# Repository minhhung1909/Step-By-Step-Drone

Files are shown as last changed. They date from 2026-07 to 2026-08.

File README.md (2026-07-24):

### 🚀 Day 1: Power Management Architecture & Schematic Design
* **Fixed & Verified Output Rails**: Finalized the power tree architecture for the 4-in-1 FOC ESC[cite: 1].
* **Buck Converter Stage (MP2359)**: Configured the step-down regulator to efficiently drop the main battery voltage down to a stable 5V rail.
* **LDO Linear Regulator Stage (MIC5219-3.3)**: Integrated the ultra-low noise LDO to convert 5V to 3.3V, ensuring a clean analog supply (`VDDA`) for the STM32G431 MCU and preventing FOC current-sensing noise.
* **Schematic Captures**: 
  * Configured proper bootstrapping components and decoupling/filtering capacitors.
  * Set up component attributes (such as DNP for optional feed-forward configurations) to keep the BOM clean for manufacturing.

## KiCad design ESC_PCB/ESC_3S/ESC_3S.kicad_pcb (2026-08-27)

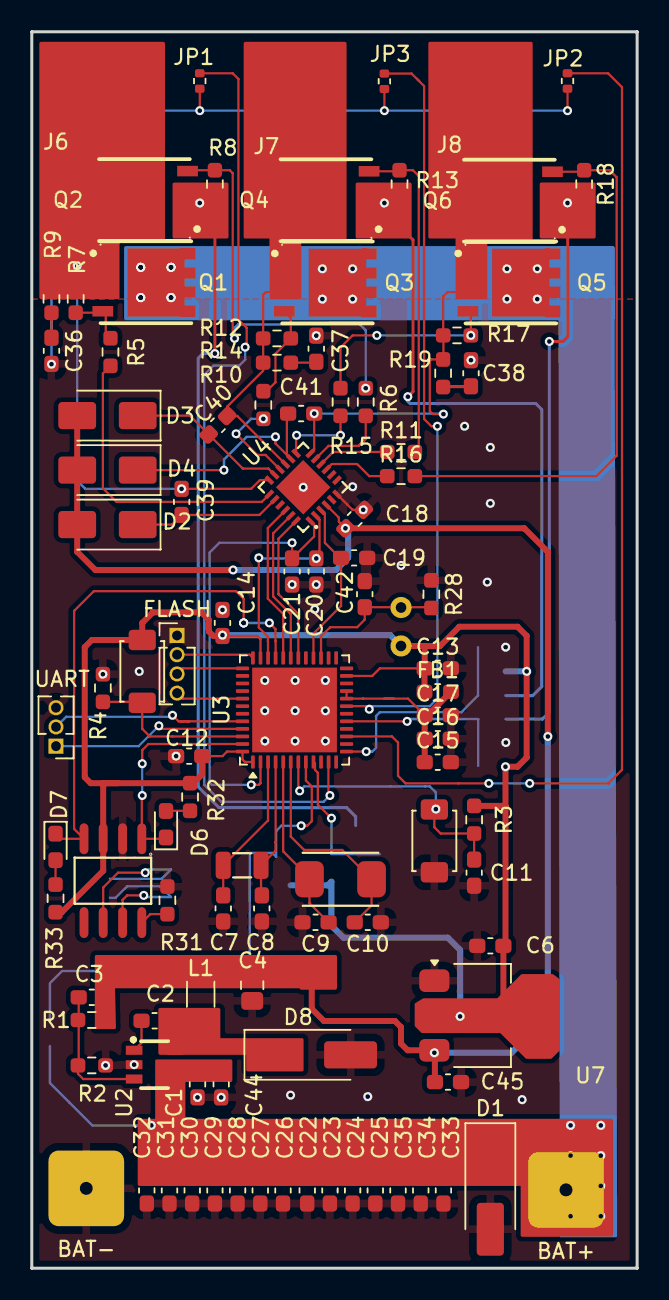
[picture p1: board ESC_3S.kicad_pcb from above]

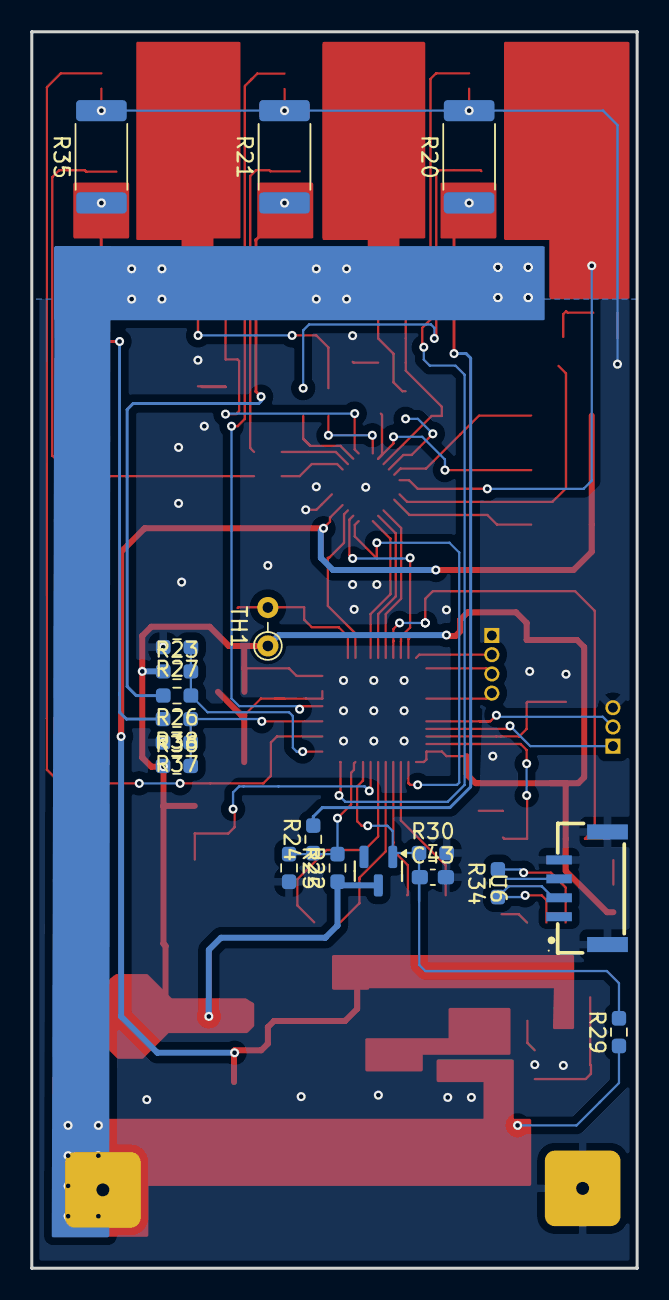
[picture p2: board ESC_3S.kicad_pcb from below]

Board: 2 copper layers, 40.0 x 81.7 mm, 119 parts (19 on the bottom side), 64 nets.

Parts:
BAT+: Conn_01x01_Pin; SolderWire-0.25sqmm_1x01_D0.65mm_OD1.7mm
BAT-: Conn_01x01_Pin; SolderWire-0.25sqmm_1x01_D0.65mm_OD1.7mm
C1: 10nF 25V; C_0603_1608Metric_Pad1.08x0.95mm_HandSolder
C2: 10nF 50V; C_0603_1608Metric_Pad1.08x0.95mm_HandSolder
C3: C; C_0603_1608Metric_Pad1.08x0.95mm_HandSolder
C4: 22uF 25V; C_0805_2012Metric_Pad1.18x1.45mm_HandSolder
C6: 10uF; C_0603_1608Metric_Pad1.08x0.95mm_HandSolder
C7, C8: 6 pF; C_0603_1608Metric_Pad1.08x0.95mm_HandSolder
C9, C10: 10 pF; C_0603_1608Metric_Pad1.08x0.95mm_HandSolder
C11, C12, C13, C14, C15, C45: 100nF; C_0603_1608Metric_Pad1.08x0.95mm_HandSolder
C16, C36, C37, C38, C42: 10nF; C_0603_1608Metric_Pad1.08x0.95mm_HandSolder
C17, C39, C40, C41: 1uF; C_0603_1608Metric_Pad1.08x0.95mm_HandSolder
C18: 470nF; C_0603_1608Metric_Pad1.08x0.95mm_HandSolder
C19, C20, C21: 100pF; C_0603_1608Metric_Pad1.08x0.95mm_HandSolder
C22, C23, C24, C25, C26, C27, C28, C29, C30, C31, C32, C33, C34, C35: 15uF; C_0603_1608Metric_Pad1.08x0.95mm_HandSolder
C43: 0.1uF; C_0603_1608Metric_Pad1.08x0.95mm_HandSolder
C44: 100nF 25V; C_0603_1608Metric_Pad1.08x0.95mm_HandSolder
D1: SMAJ18A; D_SMA_Handsoldering
D2, D3, D4: SS16; D_SMA
D5: BAT54; D_SOT-23
D6, D7: LED; LED_0603_1608Metric_Pad1.05x0.95mm_HandSolder
D8: SS34; D_SMA_Handsoldering
FB1: 600 Ohm @ 100MHz; L_0603_1608Metric_Pad1.05x0.95mm_HandSolder
FLASH: Flash&Debug; PinHeader_1x04_P1.27mm_Vertical
J6: U; SolderWirePad_1x01_SMD_1x2mm
J7: V; SolderWirePad_1x01_SMD_1x2mm
J8: W; SolderWirePad_1x01_SMD_1x2mm
JP1, JP2, JP3: SolderJumper_2_Open; R_0402_1005Metric
L1: 10uH; L_1206_3216Metric_Pad1.22x1.90mm_HandSolder
Q1, Q2, Q3, Q4, Q5, Q6: CSD18532Q5BT; SON-8_L5.0-W6.0-P1.27-BL-1
R1: 100K; R_0603_1608Metric_Pad0.98x0.95mm_HandSolder
R2, R3, R31, R32, R33: 10K; R_0603_1608Metric_Pad0.98x0.95mm_HandSolder
R4: R; R_0603_1608Metric_Pad0.98x0.95mm_HandSolder
R5, R6, R10, R11, R15, R16: 10 Ohm; R_0603_1608Metric_Pad0.98x0.95mm_HandSolder
R7, R8, R12, R13, R17, R18: 10k; R_0603_1608Metric_Pad0.98x0.95mm_HandSolder
R9, R14, R19: 1; R_0603_1608Metric_Pad0.98x0.95mm_HandSolder
R20, R21, R35: 0.003R; R_2512_6332Metric_Pad1.40x3.35mm_HandSolder
R22, R23, R36: 22K; R_0603_1608Metric_Pad0.98x0.95mm_HandSolder
R24, R26, R38: 1.5K; R_0603_1608Metric_Pad0.98x0.95mm_HandSolder
R25, R27, R37: 2.2K; R_0603_1608Metric_Pad0.98x0.95mm_HandSolder
R28: 4.7K; R_0603_1608Metric_Pad0.98x0.95mm_HandSolder
R29: 169K; R_0603_1608Metric_Pad0.98x0.95mm_HandSolder
R30: 18K; R_0603_1608Metric_Pad0.98x0.95mm_HandSolder
R34: 120R; R_0603_1608Metric_Pad0.98x0.95mm_HandSolder
S1: RESET MCU; SW_TS-1088-AR02016
S2: BOOT BTN; SW_TS-1088-AR02016
TH1: Thermistor_NTC; R_Axial_DIN0204_L3.6mm_D1.6mm_P2.54mm_Vertical
U2: MP2359; SOT-23-6_L2.9-W1.6-P0.95-LS2.8-BR
U3: STM32G431CBUx; QFN-48-1EP_7x7mm_P0.5mm_EP5.6x5.6mm
U4: FD6288Q; QFN-24_L4.0-W4.0-P0.50-BL-EP2.6
U5: SN65HVD230DR; SOIC-8_L4.9-W3.9-P1.27-LS6.0-BL
U6: SM04B-GHS-TB; CONN-SMD_4P-P1.25_SM04B-GHS-TB-LF-SN
U7: LD1117S33TR_SOT223; SOT-223-3_TabPin2
UART: UART; PinHeader_1x03_P1.27mm_Vertical
X1: Q13FC1350000400; FC-135R_L3.2-W1.5
X2: X50328MSB2GI; CRYSTAL-SMD_L5.0-W3.2

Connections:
+3.3V: C6.1, C12.1, C13.1, C14.1, D5.3, FB1.1, R3.1, R22.1, R23.1, R32.1, R33.1, R36.1, S2.1 (A), TH1.1, U3.1 (VBAT), U3.23 (VDD), U3.35 (VDD), U3.48 (VDD), U5.3 (VCC), U7.2 (VO)
+9V: C3.1, C4.1, C18.1, C45.1, D2.2 (A), D3.2 (A), D4.2 (A), L1.2, R1.1, U4.4 (VCC), U7.3 (VI)
+BATT: BAT+.1, C1.1, C22.1, C23.1, C24.1, C25.1, C26.1, C27.1, C28.1, C29.1, C30.1, C31.1, C32.1, C33.1, C34.1, C35.1, C44.1, D1.1 (A1), Q1.5 (D), Q1.6 (D), Q1.7 (D), Q1.8 (D), Q1.9 (D), Q3.5 (D), Q3.6 (D), Q3.7 (D), Q3.8 (D), Q3.9 (D), Q5.5 (D), Q5.6 (D), Q5.7 (D), Q5.8 (D), Q5.9 (D), R29.1, U2.4 (EN), U2.5 (IN)
/Addition/CAN_H: R34.1, U5.7 (CANH), U6.2
/Addition/CAN_L: R34.2, U5.6 (CANL), U6.3
/Addition/CAN_RX: D7.1 (K), U3.33 (PA11), U5.4 (R)
/Addition/CAN_TX: D6.1 (K), U3.47 (PB9), U5.1 (D)
/Addition/Temperature_fed: C42.1, R28.1, TH1.2, U3.27 (PB14)
/Addition/VBAT_SENS: C43.1, D5.1, R29.2, R30.1, U3.8 (PA0)
/Gate Driver and 3PH Inverter Bridge/Curr_fdbk1_OPAmp+: R22.2, R24.1, R25.1, U3.9 (PA1)
/Gate Driver and 3PH Inverter Bridge/Curr_fdbk2_OPAmp+: R23.2, R26.1, R27.1, U3.13 (PA5)
/Gate Driver and 3PH Inverter Bridge/Curr_fdbk3_OPAmp+: R36.2, R37.1, R38.1, U3.17 (PB0)
/Gate Driver and 3PH Inverter Bridge/HO1: R5.1, U4.19 (HO1)
/Gate Driver and 3PH Inverter Bridge/HO2: R10.1, U4.16 (HO2)
/Gate Driver and 3PH Inverter Bridge/HO3: R15.1, U4.13 (HO3)
/Gate Driver and 3PH Inverter Bridge/LO1: R6.1, U4.11 (LO1)
/Gate Driver and 3PH Inverter Bridge/LO2: R11.1, U4.10 (LO2)
/Gate Driver and 3PH Inverter Bridge/LO3: R16.1, U4.9 (LO3)
/Gate Driver and 3PH Inverter Bridge/Phase_1: C39.2, J6.1, Q1.1 (S), Q1.2 (S), Q1.3 (S), Q2.5 (D), Q2.6 (D), Q2.7 (D), Q2.8 (D), Q2.9 (D), R7.2, R9.1, U4.18 (VS1)
/Gate Driver and 3PH Inverter Bridge/Phase_2: C40.2, J7.1, Q3.1 (S), Q3.2 (S), Q3.3 (S), Q4.5 (D), Q4.6 (D), Q4.7 (D), Q4.8 (D), Q4.9 (D), R12.2, R14.1, U4.15 (VS2)
/Gate Driver and 3PH Inverter Bridge/Phase_3: C41.1, J8.1, Q5.1 (S), Q5.2 (S), Q5.3 (S), Q6.5 (D), Q6.6 (D), Q6.7 (D), Q6.8 (D), Q6.9 (D), R17.2, R19.1, U4.12 (VS3)
/Gate Driver and 3PH Inverter Bridge/TIM1_CH1: U3.30 (PA8), U4.24 (HIN3)
/Gate Driver and 3PH Inverter Bridge/TIM1_CH1N: C21.1, U3.2 (PC13), U4.1 (LIN1)
/Gate Driver and 3PH Inverter Bridge/TIM1_CH2: U3.31 (PA9), U4.23 (HIN2)
/Gate Driver and 3PH Inverter Bridge/TIM1_CH2N: C20.1, U3.34 (PA12), U4.2 (LIN2)
/Gate Driver and 3PH Inverter Bridge/TIM1_CH3: U3.32 (PA10), U4.22 (HIN1)
/Gate Driver and 3PH Inverter Bridge/TIM1_CH3N: C19.1, U3.28 (PB15), U4.3 (LIN3)
/Gate Driver and 3PH Inverter Bridge/V_Shunt_1+: Q2.1 (S), Q2.2 (S), Q2.3 (S), R8.2, R20.1, R24.2
/Gate Driver and 3PH Inverter Bridge/V_Shunt_1-: JP1.1 (A), U3.11 (PA3)
/Gate Driver and 3PH Inverter Bridge/V_Shunt_2+: Q4.1 (S), Q4.2 (S), Q4.3 (S), R13.2, R21.1, R26.2
/Gate Driver and 3PH Inverter Bridge/V_Shunt_2-: JP2.1 (A), U3.15 (PA7)
/Gate Driver and 3PH Inverter Bridge/V_Shunt_3+: Q6.1 (S), Q6.2 (S), Q6.3 (S), R18.2, R35.1, R38.2
/Gate Driver and 3PH Inverter Bridge/V_Shunt_3-: JP3.1 (A), U3.19 (PB2)
/MCU Section/BOOT0: R4.2, S2.2 (B), U3.46 (PB8)
/MCU Section/OSC32_IN: C7.1, U3.3 (PC14), X1.2
/MCU Section/OSC32_OUT: C8.1, U3.4 (PC15), X1.1
/MCU Section/OSC_IN: C9.1, U3.5 (PF0), X2.2
/MCU Section/OSC_OUT: C10.1, U3.6 (PF1), X2.1
/MCU Section/RST: C11.1, R3.2, S1.1 (A), U3.7 (PG10)
/MCU Section/RX: U3.45 (PB7), UART.1
/MCU Section/SWCLK: FLASH.3, U3.37 (PA14)
/MCU Section/SWDIO: FLASH.2, U3.36 (PA13)
/MCU Section/SWO: FLASH.4, U3.41 (PB3)
/MCU Section/TX: U3.44 (PB6), UART.2
GND: BAT-.1, C1.2, C4.2, C6.2, C7.2, C8.2, C9.2, C10.2, C11.2, C12.2, C13.2, C14.2, C15.2, C16.2, C17.2, C18.2, C19.2, C20.2, C21.2, C22.2, C23.2, C24.2, C25.2, C26.2, C27.2, C28.2, C29.2, C30.2, C31.2, C32.2, C33.2, C34.2, C35.2, C36.2, C37.2, C38.2, C42.2, C43.2, C44.2, C45.2, D1.2 (A2), D8.2 (A), FLASH.1, JP1.2 (B), JP2.2 (B), JP3.2 (B), R2.2, R4.1, R20.2, R21.2, R25.2, R27.2, R28.2, R30.2, R31.2, R35.2, R37.2, S1.2 (B), U2.2 (GND), U3.49 (VSS), U4.6 (COM), U4.25 (EP), U5.2 (GND), U6.4, U6.5, U6.6, U7.1 (GND), UART.3
unnamed: C36.1, R9.2
unnamed: C37.1, R14.2
unnamed: C38.1, R19.2
unnamed: C39.1, D2.1 (K), U4.20 (VB1)
unnamed: C40.1, D3.1 (K), U4.17 (VB2)
unnamed: C41.2, D4.1 (K), U4.14 (VB3)
unnamed: D6.2 (A), R32.2
unnamed: D7.2 (A), R33.2
unnamed: C2.2, D8.1 (K), L1.1, U2.6 (SW)
unnamed: Q1.4 (G), R5.2, R7.1
unnamed: Q2.4 (G), R6.2, R8.1
unnamed: Q3.4 (G), R10.2, R12.1
unnamed: Q4.4 (G), R11.2, R13.1
unnamed: Q5.4 (G), R15.2, R17.1
unnamed: Q6.4 (G), R16.2, R18.1
unnamed: C2.1, U2.1 (BS)
unnamed: C3.2, R1.2, R2.1, U2.3 (FB)
unnamed: R31.1, U5.8 (RS)
VDDA: C15.1, C16.1, C17.1, FB1.2, U3.20 (VREF+), U3.21 (VDDA)

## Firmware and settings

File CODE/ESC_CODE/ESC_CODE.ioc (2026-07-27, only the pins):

Mcu.UserName=STM32G431CBUx
PA0.GPIO_Label=VBAT_SENS
PA0.Signal=ADC1_IN1
PA1.Signal=OPAMP1_VINP
PA10.Signal=S_TIM1_CH3
PA11.Signal=FDCAN1_RX
PA12.Signal=TIM1_CH2N
PA13.Signal=SYS_JTMS-SWDIO
PA14.Signal=SYS_JTCK-SWCLK
PA3.Signal=OPAMP1_VINM0
PA5.Signal=OPAMP2_VINM0
PA7.Signal=OPAMP2_VINP
PA8.Signal=S_TIM1_CH1
PA9.Signal=S_TIM1_CH2
PB0.Signal=OPAMP3_VINP
PB15.Signal=TIM1_CH3N
PB2.Signal=OPAMP3_VINM0
PB3.Signal=SYS_JTDO-SWO
PB6.Signal=USART1_TX
PB7.Signal=USART1_RX
PB9.Signal=FDCAN1_TX
PC13.Signal=TIM1_CH1N
PC14-OSC32_IN.Signal=RCC_OSC32_IN
PC15-OSC32_OUT.Signal=RCC_OSC32_OUT
PF0-OSC_IN.Signal=RCC_OSC_IN
PF1-OSC_OUT.Signal=RCC_OSC_OUT

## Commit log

2026-07-27 add .ioc and temperature done sch
    [ESC_3S.kicad_sch, IVT.kicad_sch, MCUSection.kicad_sch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]
2026-07-28 done schematic
    [ESC_3S.kicad_pcb, ESC_3S.kicad_sch, IVT.kicad_sch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]
2026-07-29 dang layout
    [ESC_3S.kicad_pcb, IVT.kicad_sch, MCUSection.kicad_sch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]
2026-08-26 layout done
    [ESC_3S.kicad_pcb, IVT.kicad_sch]
2026-08-27 xuat gerber done
    [ESC_3S-B_Cu.gbr, ESC_3S-B_Mask.gbr, ESC_3S-B_Paste.gbr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]
2026-08-27 up lai pcb
    [ESC_3S.kicad_pcb]
